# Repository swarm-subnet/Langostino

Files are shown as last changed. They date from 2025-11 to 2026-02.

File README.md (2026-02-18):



<!-- PROJECT BANNER -->
<p align="center">
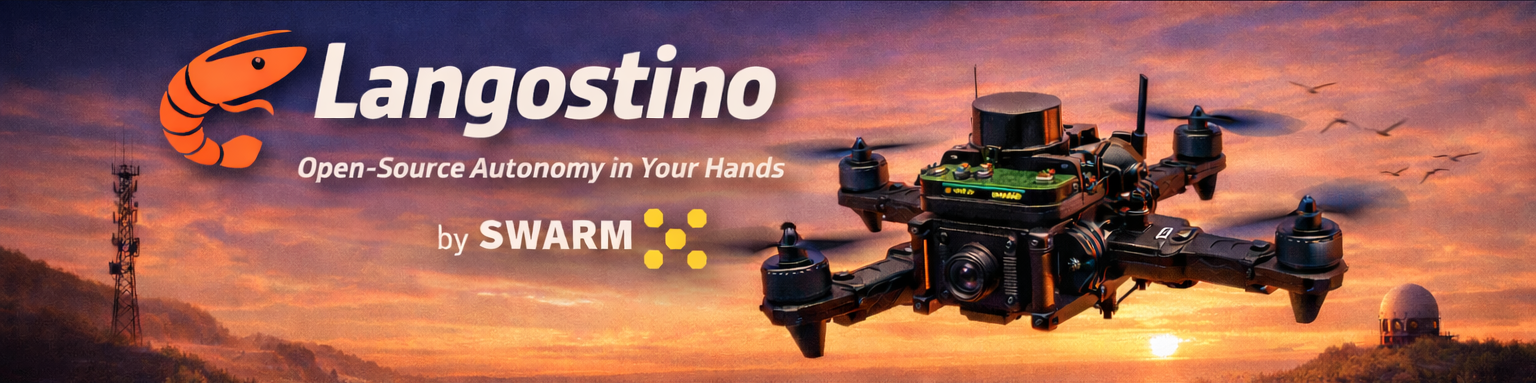
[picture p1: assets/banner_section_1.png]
Langostino — open autonomous drone
  
</p>

<h1 align="center">Langostino — The Swarm Drone</h1>

<p align="center">
  <b>Open-source AI autopilot for the real world: understand it, build it, and fly it.</b><br/>
  An open-source autonomous flight reference platform, built with a <b>global</b> community.
</p>

<!-- BADGES -->
<p align="center">
  <a href="https://github.com/swarm-subnet/Langostino/stargazers">
    
  </a>
  <a href="LICENSE.md">
    
  </a>
  
  <a href="https://discord.gg/txzvKMSd">
    
  </a>
</p>

<!-- QUICK ACTION BUTTONS -->
<p align="center">
  <a href="docs/assembly/README.md">
    
  </a>
  &nbsp;
  <a href="docs/SETUP_GUIDE.md#quick-setup">
    
  </a>
</p>

<!-- TABLE OF CONTENTS -->
<details>
  <summary><b>Table of Contents</b></summary>
  <ol>
    <li><a href="#see-it-in-action">See It In Action</a></li>
    <li><a href="#about-the-project">About The Project</a></li>
    <li><a href="#getting-started">Getting Started</a></li>
    <li><a href="#flight-plan">Flight Plan</a></li>
    <li><a href="#deep-dive-articles">Deep Dive Articles</a></li>
    <li><a href="#documentation">Documentation</a></li>
    <li><a href="#project-structure">Project Structure</a></li>
    <li><a href="#community">Community</a></li>
    <li><a href="#faq">FAQ</a></li>
    <li><a href="#share-pack">Share Pack</a></li>
    <li><a href="#license">License</a></li>
  </ol>
</details>

<!-- SEE IT IN ACTION -->
## See It In Action

### Assemble the drone and fly it autonomously

<p align="center">
  <b>"Build from scratch" drone holding its position</b>
</p>

<p align="center">
  <a href="https://www.youtube.com/shorts/gf9mxroeurU" target="_blank" rel="noopener noreferrer">
    Langostino position hold - click to watch
  </a>
</p>
<p align="center">
  <a href="https://www.youtube.com/shorts/gf9mxroeurU" target="_blank" rel="noopener noreferrer">
    
  </a>
</p>

<p align="center">
  <b>Fly it and improve it!</b>
</p>

<p align="center">
  <a href="https://www.youtube.com/watch?v=hTTbhE_WiQQ" target="_blank" rel="noopener noreferrer">
    Fly it and improve it - click to watch
  </a>
</p>
<p align="center">
  <a href="https://www.youtube.com/watch?v=hTTbhE_WiQQ" target="_blank" rel="noopener noreferrer">
    
  </a>
</p>

### Do it yourself, from ZERO!

<p align="center">
  <b>Example of what you will be building</b>
</p>

<p align="center">
  <a href="https://www.youtube.com/watch?v=jgdND4LXlIA" target="_blank" rel="noopener noreferrer">
    Langostino real flight — click to watch
  </a>
</p>
<p align="center">
  <a href="https://www.youtube.com/watch?v=jgdND4LXlIA" target="_blank" rel="noopener noreferrer">
    
  </a>
</p>

<p align="center">
  <sub>If this made you curious, star the repo and share the demo.</sub>
</p>

<p align="right">(<a href="#readme-top">back to top</a>)</p>

<!-- ABOUT THE PROJECT -->
## About The Project

Langostino is an **open-source reference drone** for real-world autonomous flight — designed to be easy to understand, build, and extend.

* **A practical AI autopilot project** focused on flying in the real world (not a black box)
* **A complete reference platform**: code, docs, and a clear path from "zero" to "first flight"
* **Made to be adapted**: use it as a starting point for your own drone and your own experiments
* **Community-driven**: built in the open, improved by builders and contributors worldwide

### Why It Matters

Autonomous drones shouldn't feel like magic or closed black boxes. Langostino exists to make real-world autonomy **understandable** and **buildable** — so more people can learn, iterate, and ship useful aerial systems.

By sharing a reference drone in the open, we lower the barrier from "curious" to "first flight", and turn progress into something the whole community can reuse.

### Built With

     

<p align="right">(<a href="#readme-top">back to top</a>)</p>

<!-- GETTING STARTED -->
## Getting Started

> [!CAUTION]
> **⚠️ Langostino is a real flying machine.**
> * Follow local regulations
> * Test in a safe environment responsibly and keep propellers off during bench tests.
> * Drones can cause injury and property damage. 
> * Use prop guards and appropriate failsafes

Pick what you want to do next — you don't need to be an expert to start.

<table>
  <tr>
    <td width="50%" valign="top">
      <h4>I'm just curious</h4>
      <ul>
        <li>Watch the demo (above)</li>
        <li>Star this repo</li>
        <li>Share it with a friend</li>
      </ul>
    </td>
    <td width="50%" valign="top">
      <h4>I want to build it from scratch</h4>
      <p><a href="docs/assembly/README.md"><b>Assembly Guide</b></a></p>
      <p><i>Includes the parts list (BOM) and step-by-step build instructions.</i></p>
    </td>
  </tr>
  <tr>
    <td width="50%" valign="top">
      <h4>I want to use the model</h4>
      <p><a href="docs/SETUP_GUIDE.md#quick-setup"><b>Setup Guide → Quick Setup</b></a></p>
    </td>
    <td width="50%" valign="top">
      <h4>I want to contribute</h4>
      <ul>
        <li>Join <a href="https://discord.gg/txzvKMSd">Discord</a></li>
        <li>Read <a href="CONTRIBUTING.md">CONTRIBUTING.md</a></li>
        <li>Pick a <a href="https://github.com/swarm-subnet/Langostino/issues?q=is%3Aissue+is%3Aopen+label%3A%22good+first+issue%22">good first issue</a></li>
      </ul>
    </td>
  </tr>
</table>

<p align="right">(<a href="#readme-top">back to top</a>)</p>

<!-- FLIGHT PLAN -->
## Flight Plan

Your path from zero to first flight:

1. **Get the parts** — Use the [BOM](docs/assembly/BOM.md) as your shopping list to source every component.

2. **Assemble the airframe** — Follow the build guide step-by-step. [Build guide →](docs/assembly/README.md)

3. **Install, then wire it up** — Follow the quickstart checklist step by step. [Quickstart →](docs/SETUP_GUIDE.md#quick-setup)

4. **Troubleshooting** — Diagnose setup, hardware, and runtime issues quickly with step-by-step checks. [Troubleshooting guide →](docs/TROUBLESHOOTING_GUIDE.md)

5. **Go outside & share** — Short flight, record a clip, star the repo, post your build. [Join Discord →](https://discord.gg/txzvKMSd)

<p align="center">
  <sub>Want the bigger picture? See the <a href="https://swarm124.com/decentralized-training">Swarm roadmap →</a></sub>
</p>

<p align="right">(<a href="#readme-top">back to top</a>)</p>

<!-- DEEP DIVE ARTICLES -->
## Deep Dive Articles

Want to understand the project in depth? Check out our Substack series that walks through every aspect of building and flying Langostino.

| Chapter | Topic | Description |
|---|---|---|
| [**Chapter 1**][chapter-1-url] | Inside the Drone | Hardware components and drone anatomy |
| [**Chapter 2**][chapter-2-url] | The Wiring Brain | Wiring, connections, and power distribution |
| [**Chapter 3**][chapter-3-url] | From Data to Motion | Software architecture and data flow |
| [**Chapter 3.5**][chapter-3.5-url] | Additional Configurations | Advanced configuration and tuning |

<p align="right">(<a href="#readme-top">back to top</a>)</p>

## Documentation

Find detailed guides for every aspect of the project.

| Category | Document | Description |
|---|---|---|
| **Building** | [Assembly Guide](docs/assembly/README.md) | Complete build guide from parts to first flight |
| | [Bill of Materials](docs/assembly/BOM.md) | Full parts list with purchase links |
| **INAV** | [INAV Configuration](docs/INAV_GUIDE.md) | Flight controller setup, PID tuning, MSP configuration |
| **ROS2** | [Setup Guide](docs/SETUP_GUIDE.md) | Ubuntu + ROS2 Humble installation on Raspberry Pi |
| | [Commands Guide](docs/COMMANDS_GUIDE.md) | ROS2 commands and node operations |
| | [Config Parameters](docs/CONFIG_PARAMS_GUIDE.md) | Complete ROS2 node configuration reference |
| **Tools** | [Map Proxy](mapproxy/README.md) | Offline map tile server for ground station |
| **Help** | [Troubleshooting](docs/TROUBLESHOOTING_GUIDE.md) | Common issues and solutions |
| | [Contributing](CONTRIBUTING.md) | How to contribute to the project |

<p align="right">(<a href="#readme-top">back to top</a>)</p>

<!-- PROJECT STRUCTURE -->
## Project Structure

<details open>
  <summary><b>Click to expand</b></summary>

```
swarm-ros/
├── src/
│   └── swarm_ai_integration/       # Main ROS2 package
│       ├── swarm_ai_integration/   # Python nodes (FC adapter, LiDAR, AI)
│       ├── config/                 # ROS2 parameter files
│       ├── launch/                 # Launch files
│       └── scripts/                # Utility scripts
├── scripts/
│   ├── setup_22_04.sh              # Ubuntu 22.04 setup script
│   ├── setup_24_04.sh              # Ubuntu 24.04 setup script
│   ├── network_setup_*.sh          # Network configuration scripts
│   ├── verify_setup.sh             # Installation verification
│   └── launch.sh                   # Quick launch script
├── docs/
│   ├── assembly/                   # Build guides and BOM
│   ├── SETUP_GUIDE.md              # ROS2 environment setup
│   ├── INAV_GUIDE.md               # Flight controller configuration
│   ├── COMMANDS_GUIDE.md           # ROS2 commands reference
│   ├── CONFIG_PARAMS_GUIDE.md      # Configuration parameters
│   └── TROUBLESHOOTING_GUIDE.md    # Common issues and fixes
├── assets/
│   └── 3D_print_STL/               # 3D printable parts (mounts, etc.)
├── inav-custom-firmware/           # Custom INAV firmware builds
├── mapproxy/                       # Offline map tile server
├── model/                          # AI model files
├── flight-logs/                    # Flight data logs
└── README.md                       # This file
```

</details>

<p align="right">(<a href="#readme-top">back to top</a>)</p>

<!-- COMMUNITY -->
## Community

Langostino is built with a **global** community of builders and contributors. If you're building, testing, or improving it — we want to hear from you.

<p align="center">
  <a href="https://discord.gg/txzvKMSd">
    
  </a>
</p>

<p align="center">
  <a href="https://discord.gg/txzvKMSd"><b>Discord</b></a>
  &nbsp;•&nbsp;
  <a href="https://x.com/SwarmSubnet"><b>X</b></a>
  &nbsp;•&nbsp;
  <a href="https://github.com/swarm-subnet"><b>GitHub</b></a>
</p>

<p align="center">
  <sub>Share your build log or flight clip in Discord — we feature the best builds.</sub>
</p>

<p align="right">(<a href="#readme-top">back to top</a>)</p>

<!-- FAQ -->
## FAQ

<details>
  <summary><b>Do I need to be an engineer?</b></summary>
  <p>No. Langostino is designed to be approachable: clear docs, a guided setup, and a community that can help you get started.</p>
</details>

<details>
  <summary><b>How do I get started?</b></summary>
  <p>Start with the <a href="docs/SETUP_GUIDE.md#quick-setup">Quick Setup Guide</a> if you already have compatible hardware. Otherwise, refer to the <a href="docs/assembly/README.md">Assembly Guide</a> for a list of materials and steps to follow. Join <a href="https://discord.gg/txzvKMSd">Discord</a> if you have any questions.</p>
</details>

<details>
  <summary><b>How do I contribute?</b></summary>
  <p>Join <a href="https://discord.gg/txzvKMSd">Discord</a>, check <a href="CONTRIBUTING.md">CONTRIBUTING.md</a>, and pick a <a href="https://github.com/swarm-subnet/Langostino/issues?q=is%3Aissue+is%3Aopen+label%3A%22good+first+issue%22">good first issue</a>.</p>
</details>

<p align="right">(<a href="#readme-top">back to top</a>)</p>

<!-- SHARE PACK -->
## Share Pack

Want to help Langostino reach more builders? Copy/paste one of these.

<details>
  <summary><b>X (Twitter)</b></summary>

  ```
  Open-source AI autopilot for real-world drones

  Langostino is a reference drone you can understand, build, and fly — built with a global community.

  https://github.com/swarm-subnet/Langostino
  ```
</details>

<details>
  <summary><b>Where to share</b></summary>

  * **Hackaday** — open hardware / DIY audience
  * **DIY Drones** — builders who actually fly
  * **Reddit** — consider: r/drones, r/Multicopter, r/robotics (follow each subreddit's rules)
</details>

<p align="right">(<a href="#readme-top">back to top</a>)</p>

<!-- LICENSE -->
## License

Distributed under the MIT License. See [LICENSE](LICENSE.md) for more information.

<p align="right">(<a href="#readme-top">back to top</a>)</p>

---

<p align="center">
  <b>Happy flying!</b>
</p>

<!-- MARKDOWN LINKS -->
[chapter-1-url]: https://substack.com/home/post/p-175604069
[chapter-2-url]: https://substack.com/home/post/p-176136139
[chapter-3-url]: https://substack.com/home/post/p-177453660
[chapter-3.5-url]: https://substack.com/home/post/p-180586067

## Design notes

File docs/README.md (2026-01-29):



# Docs folder

Quick reference index for all documentation in this folder.

## Overview

This folder contains all the documentation for setting up, configuring, and troubleshooting the Langostino drone system. Documents are organized by topic area.

## Documents Index

| Document | Description |
|---|---|
| [**assembly/**](assembly/README.md) | Complete build guide and Bill of Materials for assembling the drone from scratch |
| [**SETUP_GUIDE.md**](SETUP_GUIDE.md) | Step-by-step ROS2 environment setup on Ubuntu 22.04/24.04 for Raspberry Pi |
| [**INAV_GUIDE.md**](INAV_GUIDE.md) | Flight controller configuration: PID tuning, MSP settings, navigation parameters |
| [**COMMANDS_GUIDE.md**](COMMANDS_GUIDE.md) | Quick reference for ROS2 launch commands, PM2 management, and node operations |
| [**CONFIG_PARAMS_GUIDE.md**](CONFIG_PARAMS_GUIDE.md) | Complete reference for all ROS2 node parameters in `swarm_params.yaml` |
| [**TROUBLESHOOTING_GUIDE.md**](TROUBLESHOOTING_GUIDE.md) | Common issues and solutions for hardware, software, and network problems |

## Getting Started

**New to the project?** Start here:

1. **Building the drone** → [Assembly Guide](assembly/README.md)
2. **Setting up the software** → [Setup Guide](SETUP_GUIDE.md)
3. **Configuring the flight controller** → [INAV Guide](INAV_GUIDE.md)
4. **Running the system** → [Commands Guide](COMMANDS_GUIDE.md)

<p align="right">(<a href="#readme-top">back to top</a>)</p>

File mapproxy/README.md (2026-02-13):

# MapProxy - Satellite image map server

MapProxy, a local tile caching proxy for ArcGIS World Imagery satellite tiles. Provides satellite imagery for INAV Configurator's Mission Control with local caching to reduce bandwidth and improve loading times (so you can use it even without internet connection). If you plan to fly somewhere that is not shown on a street/basic map, you need this satellite image map.

## Installation

```bash
cd mapproxy

# Create virtual environment
python3 -m venv venv

# Activate virtual environment
source venv/bin/activate

# Install dependencies
pip install -r requirements.txt
```

## Usage

### Start the server

```bash
./launch_mapproxy.sh
```

Or manually:
```bash
source venv/bin/activate
mapproxy-util serve-develop mapproxy.yaml -b 0.0.0.0:8080
```

The server will be available at `http://localhost:8080`.

### INAV Configurator Setup

In INAV Configurator, go to **Mission Control** and configure:

| Setting | Value |
|---|---|
| Map Provider | `MapProxy` |
| MapProxy URL | `http://127.0.0.1:8080/service` |
| MapProxy Layer | `arcgis_sat` |

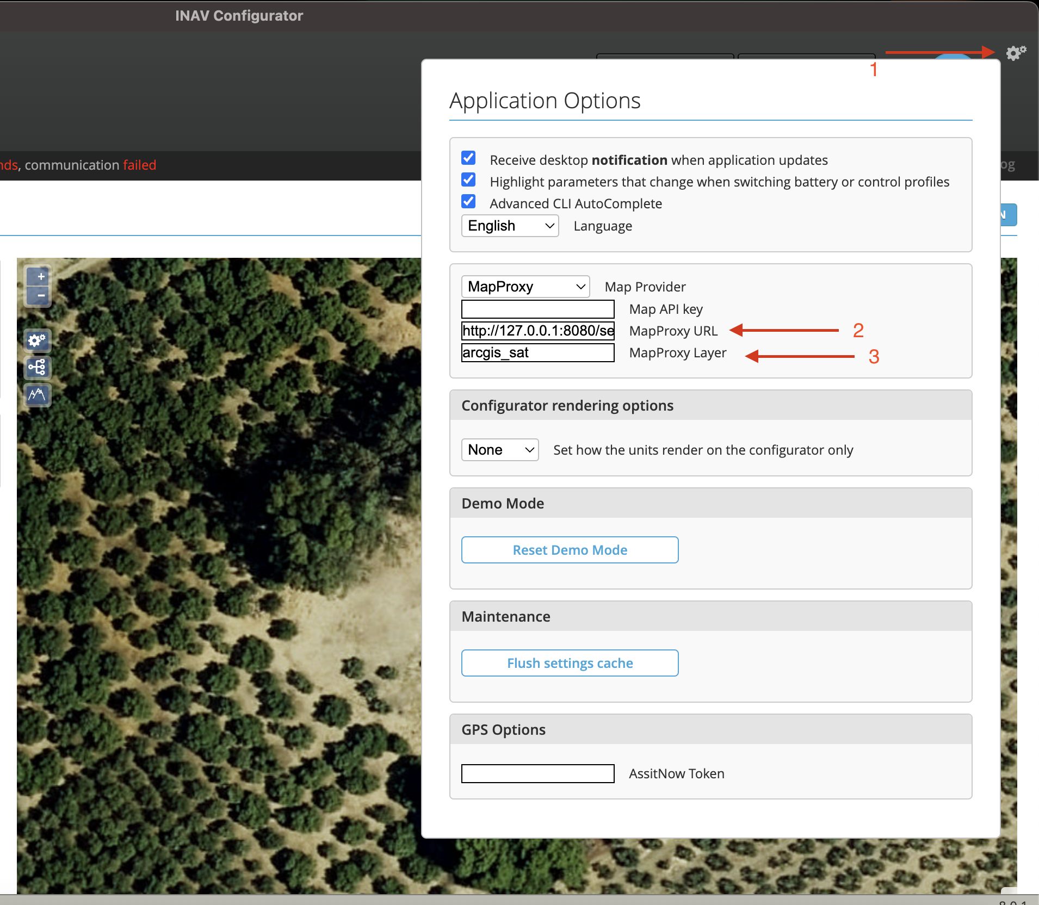
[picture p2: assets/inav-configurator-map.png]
Step to configure mapproxy on INAV configurator

_Step to configure mapproxy on INAV configurator_

### Available endpoints for testing

| Service | URL |
|---|-----|
| Demo/Preview | http://localhost:8080/demo/ |
| WMS | http://localhost:8080/service?SERVICE=WMS&REQUEST=GetCapabilities |

## Cache

Tiles are cached in `./cache_data/`. Delete this folder to clear the cache.

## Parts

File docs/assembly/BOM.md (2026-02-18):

# Parts list (BOM) — Langostino 🦐

This BOM is the parts list for a Langostino-compatible 6" quadcopter and the onboard autonomy stack (Raspberry Pi + ROS2).

## Scope

This list covers:
- All parts required to build the drone.
- Radio transmitter
- Onboard computer for ROS2 + AI stack
- Sensors and power supplier for reliable autonomy

## Core build (required)

### 1) Frame

| Part | Qty | Link | Notes |
|---|---:|---|---|
| FlyFishRC Volador II VD6 (6" carbon frame) | 1 | https://www.aliexpress.com/item/1005009244888358.html | 6" frame durable with enough room for onboard computer + sensors. |

### 2) Motors and propellers

| Part | Qty | Link | Notes |
|---|---:|---|---|
| iFlight XING-E Pro 2306 1700KV brushless motors | 4 | https://www.aliexpress.com/item/1005008310935904.html | Sized for 6" class builds. |
| HQProp 6x3x3 propellers (6CW/6CCW, 12pcs) | 1 pack | https://www.aliexpress.com/item/1005009859783537.html | Keep spare propellers for testing and tuning. |

### 3) Stack Flight controller + ESC

| Part | Qty | Link | Notes |
|---|---:|---|---|
| SpeedyBee F405 V4 + 55A 4-in-1 ESC stack (30x30) | 1 | https://www.aliexpress.com/item/1005010224729199.html | Flight controller + ESC stack. Compatible with INAV. |

### 4) GPS and compass module

| Part | Qty | Link | Notes |
|---|---:|---|---|
| HGLRC M10 GPS module + compass | 1 | https://www.aliexpress.com/item/1005008492407753.html | GPS/compass for navigation modes. Mount away from high-current wiring. |

### 5) ERLS radio transmitter and receiver

| Part | Qty | Link | Notes |
|---|---:|---|---|
| RadioMaster Boxer 2.4G ELRS transmitter | 1 | https://www.aliexpress.com/item/1005005476887648.html | Elrs and multichannel radio transmitter. |
| SpeedyBee Nano ExpressLRS receiver | 1 | https://www.aliexpress.com/item/1005009188594963.html| Receiver installed on the drone. |

### 6) Battery

| Part | Qty | Link | Notes |
|---|---:|---|---|
| Ovonic 4S LiPo 1300mAh 100C (XT60) | 1+ | https://www.aliexpress.com/item/1005009034486146.html| One battery is enough to start; multiple packs recommended for iteration. |

## Autonomy stack

### 7) Onboard computer

| Part | Qty | Link | Notes |
|---|---:|---|---|
| Raspberry Pi 5 (4GB/8GB) + case/fan | 1 | https://www.aliexpress.com/item/1005006268136678.html | Runs Ubuntu 24.04 + ROS2 Jazzy. Ensure adequate cooling. |

### 8) Clean 5V power (critical)

| Part | Qty | Link | Notes |
|---|---:|---|---|
| UBEC / switching regulator 5V (≥5A recommended) | 1 | https://www.aliexpress.com/item/1005009452713815.html | Stable 5V rail for Pi + sensors. Prefer ≥5A for Pi 5 headroom. |

## Sensors

| Part | Qty | Link | Notes |
|---|---:|---|---|
| LiDAR ToF (front-facing) | +3 | https://www.aliexpress.com/item/1005008738338495.html| Used for obstacle distance. Interface depends on model (I²C/UART). |

---

## Safety & field essentials

| Part | Qty | Link | Notes |
|---|---:|---|---|
| Autonomous buzzer / lost model buzzer | 1 | https://www.aliexpress.com/item/1005009383497649.html | Helps locate the drone after crashes or unexpected landings. It works even if the battery has been desconnected |
| Low-ESR filtering 35v 2200µf capacitor (power line) | 2 | https://www.aliexpress.com/item/1005003820087840.html| Reduces electrical noise and voltage spikes from motors/ESC. |

## Storage, wiring, and build consumables

| Part | Notes |
|---|---|
| microSD OS | 64GB min to store OS + proyect + logs
| Ethernet cable (field debugging) | Useful for direct connection to ethernet-ethernet. |
| Silicone wire awg 12 for and awg 16 for signals, heatshrink, zip ties | 
| Battery straps + foam pad | Secures LiPo during impact and vibration. |
| 3D printer | Recommended to print the files present in the `assets/3D_print_STL` folder. |

## Optional spares

| Part | Qty | Notes |
|---|---:|---|
| Extra propeller packs | 1+ | Propellers are consumables during testing. |
| Extra batteries | 1+ | More flight time per session. |

## Notes on compatibility

- This BOM targets a 6" class build (VD6 frame, 2306 motors, 6" props).
- INAV is used for navigation/autonomy features and MSP control paths.
- The autonomy stack assumes Ubuntu 25.04 + ROS2 Jazzy on a Raspberry Pi 5.

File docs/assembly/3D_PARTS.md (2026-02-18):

# 3D Printed Parts Guide

Custom 3D printed parts for mounting sensors and the companion computer on the drone frame.

> **Note:** The Raspberry Pi mount is designed for **Raspberry Pi 5**. A Raspberry Pi 3 does not fit due to the audio jack interfering with the case geometry. A version compatible with the Raspberry Pi 3 is coming soon.

---

## STL Files Location

All printable files are located in:

```
/assets/3D_print_STL/
```

---

## Parts List

### `drone-down-lidar-base.stl`

Base mount for the downward-facing LiDAR sensor. Attaches to the bottom of the drone frame.

---

### `drone-front-lidar-base.stl`

Base mount for the front-facing LiDAR sensor. On this frame, it mounts in the position originally designed for the GoPro mount.

---

### `drone-leg.stl`

Landing leg extension that fits onto the frame arm. Prevents the sensors mounted underneath from touching the ground during landing.

---

### `drone-lidar-mount.stl`

Universal LiDAR sensor mount used in both the downward and front positions. Designed so the sensor can be articulated, allowing its angle to be adjusted.

---

### `drone-raspberry-onboard-case.stl`

Case for mounting the Raspberry Pi 5 on the underside of the drone. It attaches using the screws on the lower front of the frame — the same screws that hold the metal parts originally designed for the FPV video system.

---

## Assembly Notes

The remaining components (ESCs, flight controller, receiver, etc.) should be assembled using **cable ties** and **hot silicone**, always ensuring that all parts are securely attached.

**Electromagnetic interference:** Components sensitive to electromagnetic fields, such as the **GPS** and **magnetometer**, should be mounted as far away as possible from the battery cables. For this reason:

- The **XT60 connector** is placed on the **side of the frame**.
- The **battery** is positioned **as far forward as possible**.

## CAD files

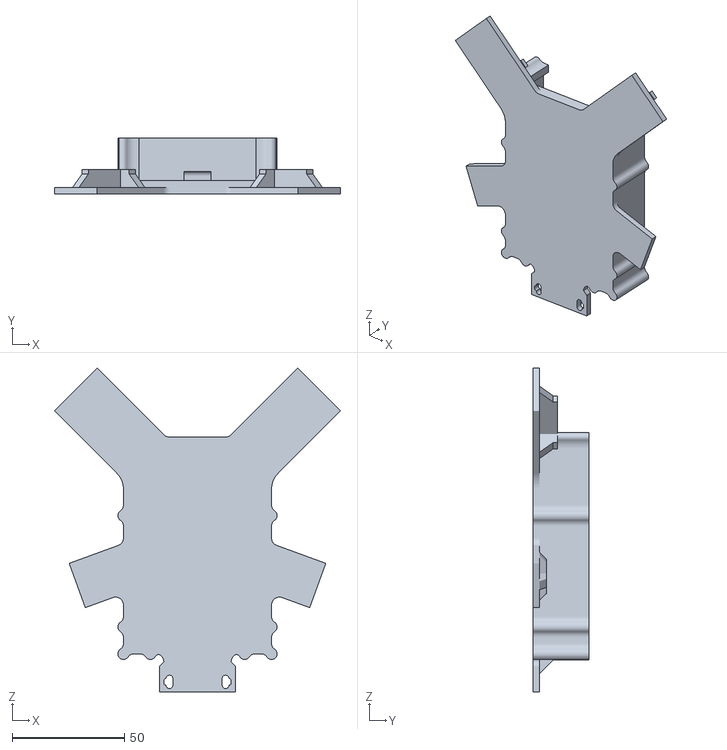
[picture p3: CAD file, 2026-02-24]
assets/3D_print_STL/drone-raspberry-onboard-case.stl
127.5 x 25.0 x 144.4

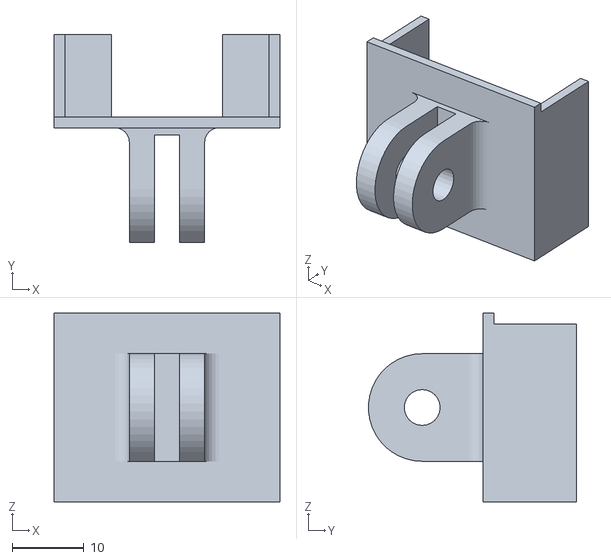
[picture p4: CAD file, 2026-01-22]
assets/3D_print_STL/drone-lidar-mount.stl
31.5 x 29.0 x 26.3

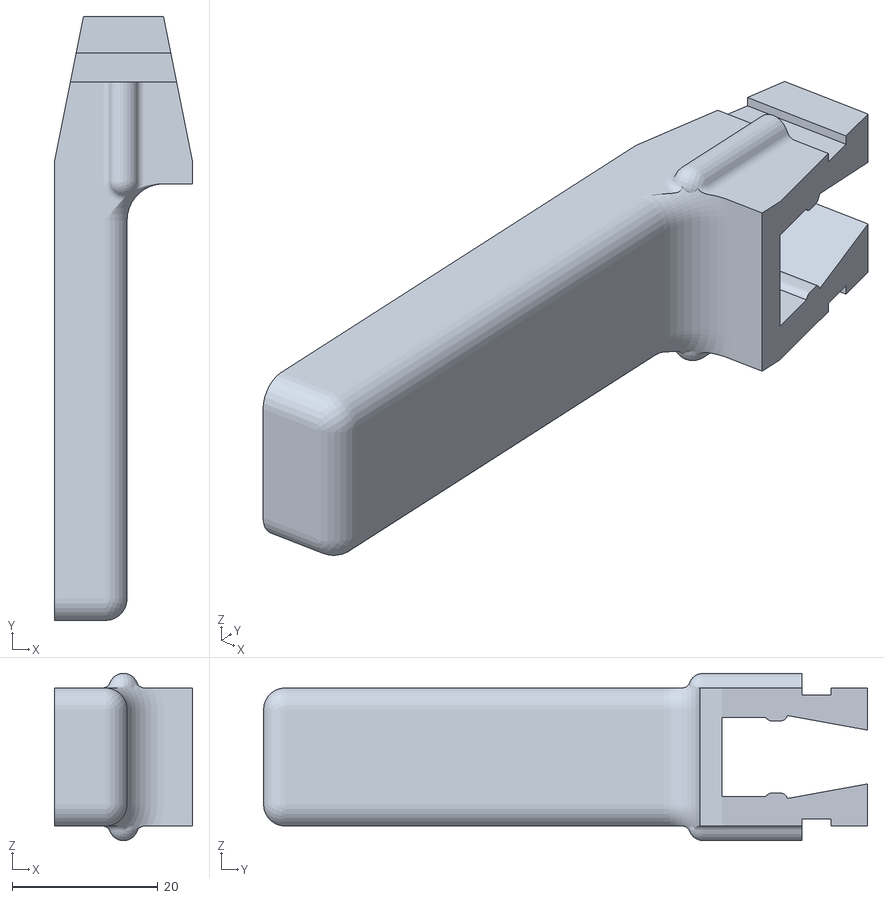
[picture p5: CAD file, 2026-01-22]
assets/3D_print_STL/drone-leg.stl
19.0 x 83.0 x 23.0

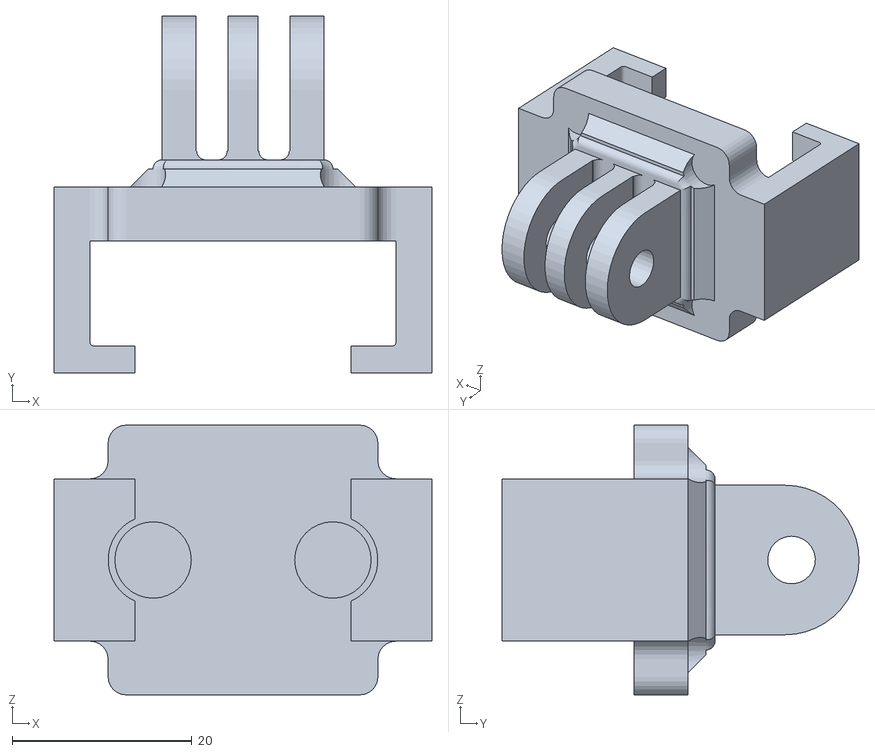
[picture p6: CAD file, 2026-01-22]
assets/3D_print_STL/drone-down-lidar-base.stl
42.0 x 39.7 x 30.0

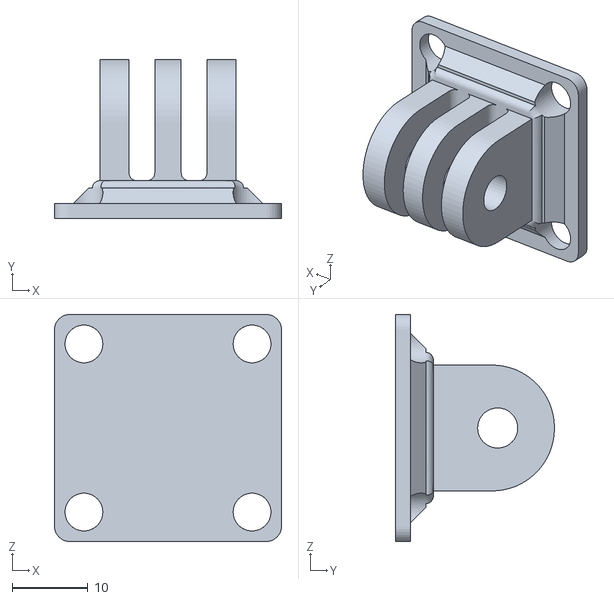
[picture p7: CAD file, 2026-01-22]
assets/3D_print_STL/drone-front-lidar-base.stl
30.0 x 21.0 x 30.0

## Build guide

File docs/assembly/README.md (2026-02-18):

# Build from scratch — Assembly guide 🦐

This guide is your “flight plan” to go from parts → build → first safe flight.

> [!CAUTION]
> **⚠️ Langostino is a real flying machine.**
> * Follow local regulations
> * Test in a safe enviroment responsibly and keep propellers off during bench tests.
> * Drones can cause injury and property damage. 
> * Use prop guards and appropriate failsafes

## Step 0 — Before you start

### Tools (typical)

- Hex drivers / screw set (FPV frame hardware)
- Soldering iron + soldering tin and flux + heatshrink
- Zip ties / cable sleeves (strain relief matters)
- Multimeter (recommended)
- Hot glue gun (recommended).
- Laptop with INAV Configurator installed and type-C USB

## Step 1 — Parts (BOM)

Open: [`./BOM.md`](./BOM.md)

The BOM is your shopping list. It should include:

- Frame
- FC/ESC stack
- Motors + propellers
- Raspberry Pi + microSD card
- LiDAR (down at least, more optional) + 3d printed mounts
- GPS/compass module
- 5V regulator + filtering capacitor
- Receiver
- Autonomous buzzer

## Step 2 — The skeleton (frame) + motors

### 2.1 Build the frame

- Assemble the carbon frame (arms, plates, standoffs)
- Keep it **rigid**: vibrations = noisy data for sensors/AI
- Leave room for: FC stack, wiring, Pi, LiDAR mounts

### 2.2 Mount motors + props (props last)

- Mount motors securely (use thread lock if needed)
- **Do not install propellers yet** — leave them off until the end

### 2.3 Install the FC + ESC stack

- Mount the stack with vibration-damping hardware if available
- Ensure access to:
  - USB port (flashing/config)
  - UART pads/ports (GPS/MSP/etc.)
  - power leads (battery input)

> Why INAV: unlike Betaflight (manual-first), **INAV** is built for navigation/autonomy and supports MSP-based control paths.

## Step 3 — Sensors + “field” essentials

### 3.1 LiDAR

- Install LiDAR downward-facing (front-facing optional)
- Use stable mounts (3D-printed mounts help reduce vibration + keep alignment)
- Keep cables tidy and strain-relieved
- See [`3D_PARTS.md`](./3D_PARTS.md) for printable sensor mounts and assembly notes

### 3.2 GPS

- Mount the GPS with good sky visibility
- Keep it away from noisy power lines, like awg 12 battery wires if possible

### 3.3 Receiver

- Install a receiver so you can always take back control
- Confirm that you have a good control before autonomy flights

### 3.4 Autonomous buzzer (highly recommended)

- Install an autonomous buzzer connected to the FC on BZ+ and BZ-.
- Purpose: finding the drone after unexpected landings/crashes

## Step 4 — Wiring (power + data)

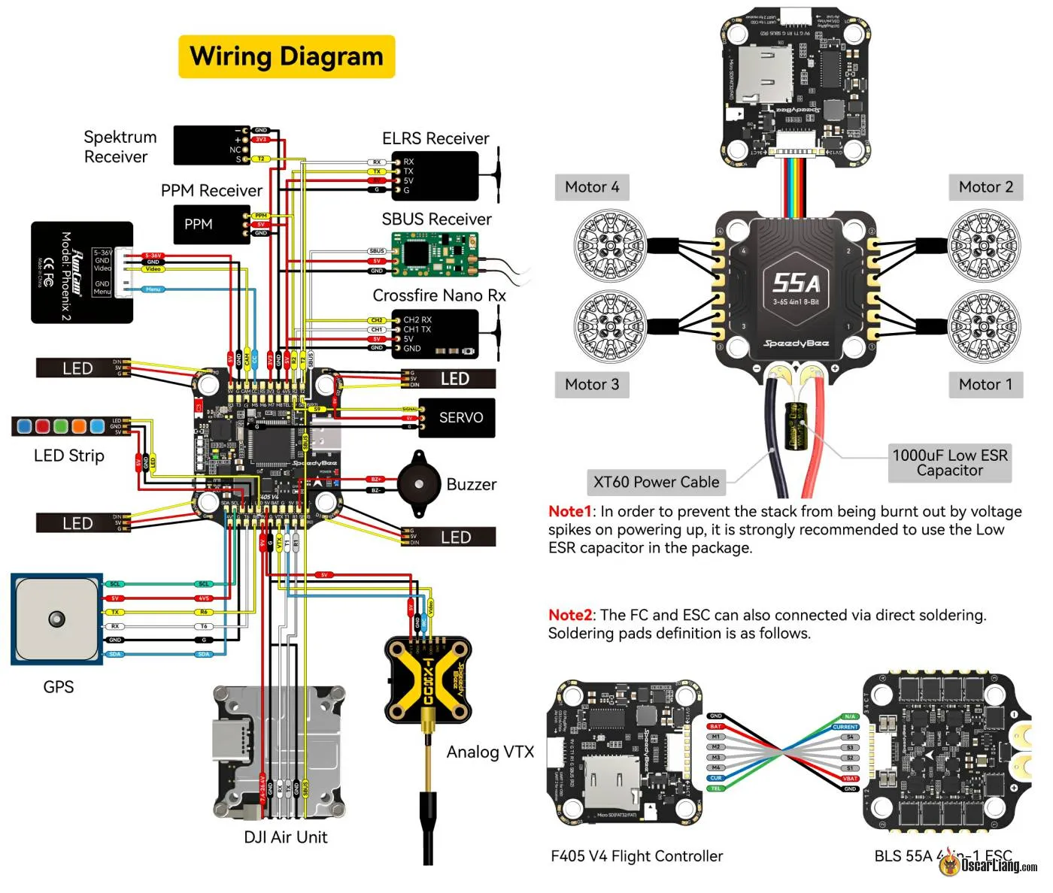
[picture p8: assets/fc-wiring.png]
SpeedyBee F405 V4 wiring diagram

_SpeedyBee F405 V4 wiring diagram_

This is where "circuits meet code".

> 📖 **Deep Dive:** For a detailed walkthrough of the wiring and connections, see [Chapter 2: The Wiring Brain](https://substack.com/home/post/p-176136139) on our Substack.

### 4.1 Clean power (very important)

- Battery feeds ESC → motors
- A regulator steps down high voltage to **clean 5V** for the Raspberry Pi.
- Add a **filtering capacitor** on the power line:
  - reduces electrical noise from motors
  - helps protect electronics from voltage spikes

> If power is noisy, sensors can drift and the AI can “react” to bad data.

### 4.2 Data buses: UART + I²C

#### UART (direct “hotline”)

Used for FC ↔ Raspberry Pi (telemetry + commands).

- On the Pi, stable device paths often look like `/dev/ttyAMA0` / `/dev/ttyAMA1`
- Keep UART wiring short/clean where possible

##### FC UART assignments

| UART | Function |
|---|---|
| UART 2 | ELRS receiver |
| UART 3 | FC to Raspberry Pi communications |
| UART 4 | Not used |
| UART 5 | Internal telemetry with ESCs |
| UART 6 | GPS and compass |

#### I²C (shared "group chat")

Used for multiple sensors on the same bus.

- LiDAR modules communicate via I²C
- Each has its own address so they don't collide

#### Raspberry Pi 5 GPIO Connections

<p align="center">
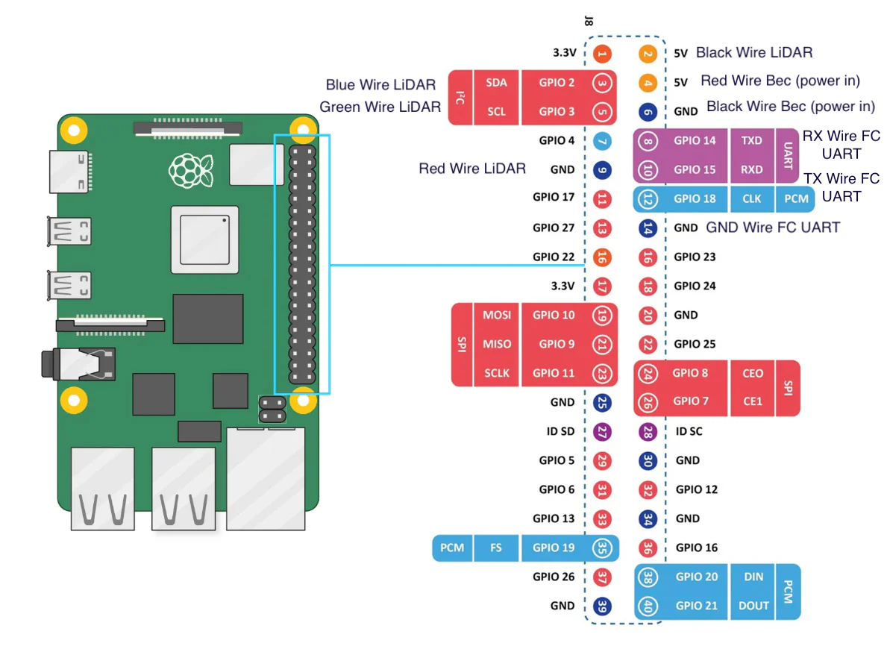
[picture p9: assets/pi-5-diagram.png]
Raspberry Pi 5 GPIO diagram
  
</p>

| Pin | Function | Connection |
|-----|---|---|
| 2 | 5V VCC | LiDAR power |
| 3 | SDA (I²C) | LiDAR SDA |
| 4 | 5V | Raspberry Pi power input |
| 5 | SCL (I²C) | LiDAR SCL |
| 6 | GND | Raspberry Pi power GND |
| 8 | TXD (UART) | FC RX |
| 9 | GND | LiDAR GND |
| 10 | RXD (UART) | FC TX |
| 14 | GND | FC UART GND |

> **Note:** TXD → RX and RXD → TX: UART lines cross between devices.

## Step 5 — Raspberry Pi software (Ubuntu + ROS2 + Swarm stack)

Follow the quick setup:
[`../SETUP_GUIDE.md#quick-setup`](../SETUP_GUIDE.md#quick-setup)

In most cases you’ll run:

```bash
sudo ./setup.sh
./verify_setup.sh
./launch.sh
```

If you hit issues, go to:
[`../TROUBLESHOOTING_GUIDE.md`](../TROUBLESHOOTING_GUIDE.md)

## Step 6 — INAV setup (firmware + parameters + MSP path)

### 6.1 Flash INAV (if not already)

- Use INAV Configurator firmware flasher
- Flash a supported INAV build for your flight controller. For SpeedyBee F405 V4, use our custom firmware: [`inav_8.0.1_SPEEDYBEEF405V4.hex`](../../inav-custom-firmware/inav_8.0.1_SPEEDYBEEF405V4.hex)
- Reboot and confirm the FC connects properly

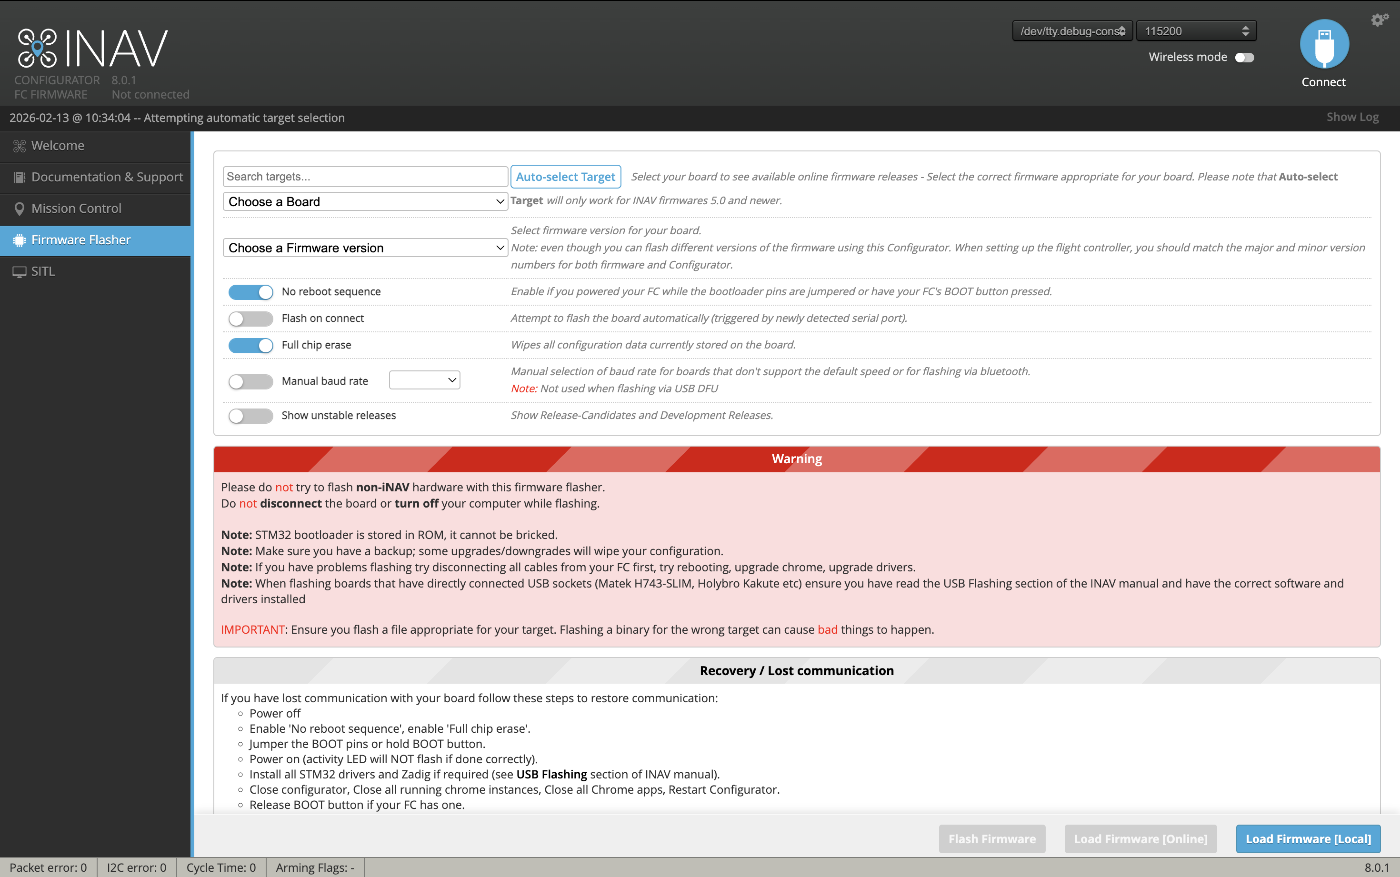
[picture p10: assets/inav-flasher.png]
Flasher option of INAV configurator

_Flasher option of INAV configurator_

### 6.2 Apply baseline parameters (copy/paste script)

Use:
[`../INAV_GUIDE.md#complete-configuration-script-inav-cli-commands`](../INAV_GUIDE.md#complete-configuration-script-inav-cli-commands)

### 6.3 MSP / RC override

From [`../INAV_GUIDE.md#msp-configuration`](../INAV_GUIDE.md#msp-configuration):

- `msp_override_channels` defines which RC channels can be overridden via MSP.

**Build-guide checklist (repo-confirmed + typical practice):**

- Configure your INAV parameters (script above)
- Set `msp_override_channels` as documented (e.g. `127` or `255` depending on your channel plan)
- Ensure you have a working manual override (radio receiver) before autonomy tests

> Note: enabling MSP/override end-to-end often involves both **parameters** (like `msp_override_channels`) and **port configuration** in INAV Configurator. Port specifics vary by FC and wiring.

## First flights (do this in order)

### Bench test (props off)

- Power on, confirm FC boots normally
- Confirm sensors are detected (as per setup docs)
- Run [`../../scripts/verify_setup.sh`](../../scripts/verify_setup.sh)
- Confirm launch is stable and logs are clean
- Confirm motor spin direction. Set reverse motor spin direction to follow this diagram:

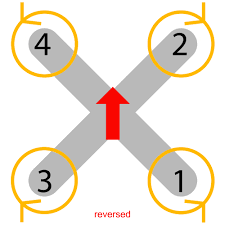
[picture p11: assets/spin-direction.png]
Spin direction

_Drone motor spin direction_

> **Fixing wrong motor direction:** If any motor spins the wrong way, you can reverse it using the [ESC Configurator](https://esc-configurator.com). Connect the FC via USB, open the tool in a Chrome-based browser, select your ESC firmware (BLHeli_S / BLHeli_32 / AM32), and toggle the **Motor Direction** for the affected motor(s). Flash the updated settings and verify the correct spin direction.

### Manual flight first

Before autonomy:

- Confirm arming checks pass
- Confirm vibrations are reasonable
- Confirm GPS meets minimum sats and is stable
- Confirm flight mode works

### Then autonomy experiments

- Start conservative
- Keep safe altitude and space
- Log everything and iterate

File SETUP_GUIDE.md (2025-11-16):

# Swarm ROS2 Environment Setup Guide

This guide provides step-by-step instructions for setting up the complete Swarm AI Integration drone control system on Ubuntu 22.04.

## Table of Contents

- [Prerequisites](#prerequisites)
- [Quick Setup](#quick-setup)
- [Manual Setup](#manual-setup)
- [Hardware Configuration](#hardware-configuration)
- [Verification](#verification)
- [Troubleshooting](#troubleshooting)

---

## Prerequisites

### Hardware Requirements
- **Flight Controller**: INAV 7 compatible (connected via UART/Serial)
- **LiDAR Sensor**: I2C-based distance sensor (e.g., TFMini-S on address 0x08)
- **Onboard Computer**: Raspberry Pi 4 or Ubuntu 22.04 server
- **GPS Module**: Connected to flight controller
- **IMU**: Integrated in flight controller

### Software Requirements
- **OS**: Ubuntu 22.04 LTS (Jammy Jellyfish)
- **Internet Connection**: For downloading packages
- **Sudo Access**: Root privileges required for installation

### Hardware Connections
| Component | Interface | Device Path | Notes |
|---|---|---|---|
| Flight Controller | UART/Serial | `/dev/ttyAMA0` | 115200 baud |
| LiDAR (Down) | I2C Bus 1 | Address `0x08` | 100Hz polling |
| GPS | via FC | - | MSP protocol |
| IMU | via FC | - | MSP protocol |

---

## Quick Setup

### 1. Clone the Repository

```bash
cd ~
git clone <your-repo-url> swarm-ros
cd swarm-ros
```

### 2. Run Setup Script

```bash
sudo ./setup.sh
```

**What it does:**
- ✅ Installs ROS2 Humble (if needed)
- ✅ Installs all dependencies (Python, I2C, UART)
- ✅ Creates Python virtual environment for AI packages
- ✅ Configures hardware permissions (I2C, UART)
- ✅ **Configures network (WiFi AP + Ethernet static IP)**
- ✅ **Fixes workspace ownership** (prevents permission errors)
- ✅ Builds ROS2 workspace
- ✅ Installs PM2 process manager (auto-start on boot)

**Available Options:**
- `--skip-ros`: Skip ROS2 installation (if already installed)
- `--skip-hardware-check`: Skip hardware connectivity checks
- `--skip-pm2`: Skip PM2 installation (installed by default)

**Example with options:**
```bash
# Skip PM2 if you don't want process management
sudo ./setup.sh --skip-pm2

# Skip ROS2 install if already present
sudo ./setup.sh --skip-ros
```

> **Note**: The script automatically fixes workspace permissions and cleans old build artifacts, preventing common `colcon build` permission errors.

### 3. Log Out and Back In

**Important**: You must log out and log back in for group changes to take effect!

```bash
logout
# Or reboot
sudo reboot
```

### 4. Verify Installation

```bash
cd ~/swarm-ros
./verify_setup.sh
```

### 5. Launch the System

**Option A: Using PM2 (Recommended - Auto-installed)**

```bash
# Launch with PM2 process manager
./launch.sh

# View status
pm2 list

# View logs in real-time
pm2 logs

# Stop the system
pm2 stop swarm-ros-launched
```

**Option B: Direct ROS2 Launch**

```bash
# Source the environment (if not in .bashrc)
source /opt/ros/humble/setup.bash
source ~/swarm-ros/install/setup.bash

# Launch directly (runs in foreground)
ros2 launch swarm_ai_integration swarm_ai_launch.py
```

> **PM2 Benefits**: Auto-restart on crash, survives reboots, centralized logging, resource monitoring

---

## Manual Setup

If you prefer to set up components individually:

### Step 1: Install ROS2 Humble

```bash
# Set up locale
sudo apt update && sudo apt install -y locales
sudo locale-gen en_US en_US.UTF-8
sudo update-locale LC_ALL=en_US.UTF-8 LANG=en_US.UTF-8

# Add ROS2 apt repository
sudo apt install -y software-properties-common
sudo add-apt-repository universe
sudo apt update && sudo apt install -y curl gnupg lsb-release

curl -sSL https://raw.githubusercontent.com/ros/rosdistro/master/ros.key \
  -o /usr/share/keyrings/ros-archive-keyring.gpg

echo "deb [arch=$(dpkg --print-architecture) signed-by=/usr/share/keyrings/ros-archive-keyring.gpg] \
  http://packages.ros.org/ros2/ubuntu $(source /etc/os-release && echo $UBUNTU_CODENAME) main" \
  | sudo tee /etc/apt/sources.list.d/ros2.list > /dev/null

# Install ROS2
sudo apt update
sudo apt install -y ros-humble-ros-base
sudo apt install -y ros-dev-tools python3-colcon-common-extensions

# Initialize rosdep
sudo rosdep init
rosdep update
```

### Step 2: Install System Dependencies

```bash
sudo apt install -y \
    build-essential \
    cmake \
    git \
    python3-pip \
    python3-dev \
    python3-venv \
    libi2c-dev \
    i2c-tools \
    python3-smbus \
    python3-serial \
    python3-numpy \
    python3-scipy
```

### Step 3: Install Python Dependencies

**System packages (for ROS nodes):**
```bash
pip3 install --upgrade pip
pip3 install numpy scipy pyserial smbus2
```

**Virtual environment for AI Flight Node:**
```bash
# Create virtual environment
python3 -m venv ~/ai_flight_node_env

# Activate virtual environment
source ~/ai_flight_node_env/bin/activate

# Install AI packages from requirements file
cd ~/swarm-ros
pip install --upgrade pip
pip install -r ai_model_requirements.txt

# Deactivate (optional)
deactivate
```

The `ai_model_requirements.txt` file contains:
- numpy>=1.24,<2.0
- typing-extensions
- gymnasium
- stable-baselines3
- torch

### Step 4: Configure I2C (for LiDAR)

```bash
# Enable I2C module
sudo modprobe i2c-dev
echo "i2c-dev" | sudo tee -a /etc/modules

# Add user to i2c group
sudo usermod -a -G i2c $USER

# Set I2C permissions
echo 'KERNEL=="i2c-[0-9]*", GROUP="i2c", MODE="0660"' \
  | sudo tee /etc/udev/rules.d/99-i2c.rules

sudo udevadm control --reload-rules
sudo udevadm trigger
```

### Step 5: Configure UART (for Flight Controller)

```bash
# Add user to dialout group
sudo usermod -a -G dialout $USER

# Set UART permissions
cat << EOF | sudo tee /etc/udev/rules.d/99-serial.rules
KERNEL=="ttyAMA[0-9]*", GROUP="dialout", MODE="0660"
KERNEL=="ttyUSB[0-9]*", GROUP="dialout", MODE="0660"
KERNEL=="ttyACM[0-9]*", GROUP="dialout", MODE="0660"
EOF

sudo udevadm control --reload-rules
sudo udevadm trigger
```

### Step 6: Configure Network (WiFi AP + Ethernet)

```bash
# Run the network setup script
cd ~/swarm-ros
chmod +x network_setup.sh
sudo ./network_setup.sh
```

**What it configures:**
- Static IP on `eth0`: `192.168.10.1/24`
- DHCP on `wlan0` for connecting to known WiFi networks
- Automatic WiFi Access Point fallback
- AP SSID: `Swarm_AP`
- AP Password: `swarmascend`
- DHCP server range: `192.168.10.10 - 192.168.10.50`
- Automatic network manager service

The system will automatically:
1. Try to connect to known WiFi networks on boot
2. If no known network is found, create an Access Point
3. Allow you to SSH into the drone at `192.168.10.1`

To add known WiFi networks, edit `/etc/wifi_networks.conf`:
```bash
sudo nano /etc/wifi_networks.conf
```

Add networks in the format:
```
SSID:password
MyHomeWiFi:mypassword123
WorkNetwork:workpassword
```

### Step 7: Build ROS2 Workspace

```bash
cd ~/swarm-ros
source /opt/ros/humble/setup.bash
rosdep install --from-paths src --ignore-src -r -y
colcon build --symlink-install
```

### Step 8: Configure Environment

Add to `~/.bashrc`:

```bash
# ROS2 Environment
source /opt/ros/humble/setup.bash
source ~/swarm-ros/install/setup.bash

# ROS2 Configuration
export ROS_DOMAIN_ID=0
export ROS_LOCALHOST_ONLY=0
```

Apply changes:
```bash
source ~/.bashrc
```

---

## Hardware Configuration

### I2C LiDAR Setup

#### Enable I2C on Raspberry Pi

Edit `/boot/firmware/config.txt`:
```bash
sudo nano /boot/firmware/config.txt
```

Add or uncomment:
```
dtparam=i2c_arm=on
```

Reboot:
```bash
sudo reboot
```

#### Verify I2C Connection

Check if I2C device is detected:
```bash
i2cdetect -y 1
```

You should see `08` in the output grid (LiDAR address).

### UART Flight Controller Setup

#### Enable UART on Raspberry Pi

Edit `/boot/firmware/config.txt`:
```bash
sudo nano /boot/firmware/config.txt
```

Add:
```
enable_uart=1
```

#### Disable Serial Console (if needed)

Edit `/boot/firmware/cmdline.txt` and remove:
```
console=serial0,115200
```

#### Verify UART Connection

```bash
ls -l /dev/ttyAMA0
```

Should show device with `crw-rw----` permissions and group `dialout`.

### Network Setup

The Swarm system is configured with a dual-network setup for maximum flexibility:

#### Network Interfaces

| Interface | Mode | IP Address | Purpose |
|---|---|---|---|
| `eth0` | Static IP | `192.168.10.1/24` | Main communication interface |
| `wlan0` | DHCP/AP | Auto/`192.168.10.1` | WiFi client or Access Point |

#### WiFi Auto-Manager

The system includes an automatic WiFi manager that:
1. **Scans** for known WiFi networks on boot
2. **Connects** to the first available known network (client mode)
3. **Falls back** to Access Point mode if no known networks found

#### Access Point Details

When in AP mode:
- **SSID**: `Swarm_AP`
- **Password**: `swarmascend`
- **IP Address**: `192.168.10.1`
- **DHCP Range**: `192.168.10.10 - 192.168.10.50`

#### Connect to the Swarm

**Via Access Point:**
```bash
# Connect your laptop to Swarm_AP WiFi network
# Password: swarmascend

# SSH into the drone
ssh pi@192.168.10.1
```

**Via Ethernet:**
```bash
# Connect ethernet cable to your laptop
# Configure your laptop's ethernet to 192.168.10.x (x != 1)

# SSH into the drone
ssh pi@192.168.10.1
```

#### Add Known WiFi Networks

Edit the known networks file:
```bash
sudo nano /etc/wifi_networks.conf
```

Add networks (one per line):
```
SSID:password
MyHomeWiFi:mypassword123
WorkNetwork:workpassword
```

Restart the WiFi manager service:
```bash
sudo systemctl restart wifi-manager.service
```

#### Network Service Management

```bash
# Check WiFi manager status
sudo systemctl status wifi-manager.service

# View WiFi manager logs
sudo journalctl -u wifi-manager.service -f

# Manually start Access Point
sudo systemctl start hostapd
sudo systemctl start dnsmasq

# Manually stop Access Point
sudo systemctl stop hostapd
sudo systemctl stop dnsmasq

# Check current network status
ip addr show
iwconfig
```

---

## Verification

### Run Verification Script

```bash
cd ~/swarm-ros
./verify_setup.sh
```

The script checks:
- ✓ Ubuntu version
- ✓ ROS2 Humble installation
- ✓ Python dependencies
- ✓ I2C configuration and LiDAR detection
- ✓ UART configuration and FC connection
- ✓ Workspace build status
- ✓ Launch files and configuration

### Manual Hardware Tests

#### Test I2C Communication

```bash
# Scan I2C bus
i2cdetect -y 1

# Read from LiDAR (if using i2c-tools)
i2cget -y 1 0x08 0x24 w
```

#### Test UART Communication

```bash
# Check if device is accessible
ls -l /dev/ttyAMA0

# Monitor serial data (Ctrl+C to exit)
cat /dev/ttyAMA0
```

#### Test ROS2 Nodes

```bash
# Source environment
source /opt/ros/humble/setup.bash
source ~/swarm-ros/install/setup.bash

# List available nodes
ros2 pkg executables swarm_ai_integration

# Test individual node
ros2 run swarm_ai_integration lidar_reader_node
```

---

## Troubleshooting

### ROS2 Issues

**Problem**: `ros2: command not found`

**Solution**:
```bash
source /opt/ros/humble/setup.bash
# Add to ~/.bashrc to make permanent
```

**Problem**: Package not found after building

**Solution**:
```bash
cd ~/swarm-ros
rm -rf build install log
colcon build --symlink-install
source install/setup.bash
```

### I2C Issues

**Problem**: `Could not open file /dev/i2c-1: Permission denied`

**Solution**:
```bash
# Add user to i2c group
sudo usermod -a -G i2c $USER
# Log out and back in
```

**Problem**: No device at address 0x08

**Solution**:
- Check LiDAR is powered on
- Verify wiring (SDA, SCL, VCC, GND)
- Check if I2C is enabled in config.txt
- Try scanning: `i2cdetect -y 1`

### UART Issues

**Problem**: `/dev/ttyAMA0: Permission denied`

**Solution**:
```bash
# Add user to dialout group
sudo usermod -a -G dialout $USER
# Log out and back in
```

**Problem**: UART device not found

**Solution**:
- Check UART is enabled in `/boot/firmware/config.txt`
- Verify physical connection to flight controller
- Try alternative devices: `/dev/ttyUSB0` or `/dev/ttyACM0`
- Update config in `swarm_params.yaml`:
  ```yaml
  fc_comms_node:
    ros__parameters:
      serial_port: "/dev/ttyUSB0"  # Change as needed
  ```

### Build Issues

**Problem**: `Permission denied: 'log/build_XXXX'` when running `colcon build`

**Solution**:
```bash
# Fix ownership of workspace (happens if you ran setup with sudo)
cd ~/swarm-ros
sudo chown -R $USER:$USER ~/swarm-ros

# Clean old build artifacts
rm -rf log build install

# Rebuild
colcon build --symlink-install
```

> **Note**: The latest setup.sh automatically fixes this, but if you encounter it, run the commands above.

**Problem**: CMake or compilation errors

**Solution**:
```bash
# Install missing dependencies
rosdep install --from-paths src --ignore-src -r -y

# Clean and rebuild
cd ~/swarm-ros
rm -rf build install log
colcon build --symlink-install
```

**Problem**: Python import errors

**Solution**:
```bash
# Reinstall system Python dependencies
pip3 install --upgrade numpy scipy pyserial smbus2

# Reinstall AI packages in virtual environment
source ~/ai_flight_node_env/bin/activate
pip install --upgrade pip
pip install -r ~/swarm-ros/ai_model_requirements.txt
deactivate
```

**Problem**: Virtual environment not found or in wrong location (`/root/ai_flight_node_env`)

**Solution**:
```bash
# Remove incorrectly located venv
sudo rm -rf /root/ai_flight_node_env

# Create venv in correct location (as pi user)
python3 -m venv ~/ai_flight_node_env
~/ai_flight_node_env/bin/pip install --upgrade pip
~/ai_flight_node_env/bin/pip install -r ~/swarm-ros/ai_model_requirements.txt
```

> **Note**: The latest setup.sh creates the venv in the correct user's home directory automatically.

### Network Issues

**Problem**: Cannot connect to Swarm_AP WiFi

**Solution**:
```bash
# Check if WiFi manager service is running
sudo systemctl status wifi-manager.service

# Check if hostapd and dnsmasq are running (AP mode)
sudo systemctl status hostapd
sudo systemctl status dnsmasq

# Restart WiFi manager
sudo systemctl restart wifi-manager.service

# Check logs
sudo journalctl -u wifi-manager.service -f
```

**Problem**: WiFi not switching to known network

**Solution**:
```bash
# Verify known networks file exists
cat /etc/wifi_networks.conf

# Check for typos in SSID or password
sudo nano /etc/wifi_networks.conf

# Restart WiFi manager
sudo systemctl restart wifi-manager.service

# Manually scan for networks
nmcli dev wifi list
```

**Problem**: Ethernet connection not working

**Solution**:
```bash
# Check eth0 configuration
ip addr show eth0

# Verify static IP is set to 192.168.10.1
# Should show: inet 192.168.10.1/24

# Check Netplan configuration
cat /etc/netplan/99-swarm-network.yaml

# Reapply Netplan configuration
sudo netplan apply

# Verify your laptop's ethernet is in the same subnet (192.168.10.x)
```

**Problem**: Cannot SSH to 192.168.10.1

**Solution**:
```bash
# Verify you're connected to Swarm_AP or ethernet
# Check your IP address (should be 192.168.10.x)
ip addr

# Ping the drone
ping 192.168.10.1

# Check if SSH is running on the drone
sudo systemctl status ssh

# Try connecting with verbose output
ssh -vvv pi@192.168.10.1
```

### Runtime Issues

**Problem**: Nodes crash on startup

**Solution**:
- Check logs: `ros2 topic echo /rosout`
- Verify hardware is connected
- Check configuration in `config/swarm_params.yaml`
- Run verification: `./verify_setup.sh`

**Problem**: No GPS fix

**Solution**:
- Move to open sky location
- Wait 30-60 seconds for GPS lock
- Check GPS satellites: `ros2 topic echo /fc/gps_satellites`
- Verify HDOP: `ros2 topic echo /fc/gps_hdop`

---

## Configuration Files

### Main Configuration

**Location**: `src/swarm_ai_integration/config/swarm_params.yaml`

Key parameters to configure:
- Flight controller serial port
- LiDAR I2C address
- Safety limits (altitude, velocity, battery)
- AI model path

### Launch Configuration

**Location**: `src/swarm_ai_integration/launch/swarm_ai_launch.py`

Modify to enable/disable nodes as needed.

---

## Process Management with PM2

PM2 is **installed by default** by the setup script and provides powerful process management features.

### Quick Start

```bash
# Start the ROS system with PM2
./launch.sh

# Check status
pm2 list
```

### Common PM2 Commands

```bash
# View logs in real-time (all processes)
pm2 logs

# View logs for specific process
pm2 logs swarm-ros-launched

# Monitor resource usage (CPU, memory)
pm2 monit

# Stop the system
pm2 stop swarm-ros-launched

# Restart the system
pm2 restart swarm-ros-launched

# Stop all PM2 processes
pm2 stop all

# Restart all PM2 processes
pm2 restart all

# Delete process from PM2
pm2 delete swarm-ros-launched

# Show detailed process info
pm2 show swarm-ros-launched
```

### Auto-Start on Boot

PM2 is **automatically configured** to start on boot by the setup script:

```bash
# Verify startup configuration
pm2 startup

# Save current process list (auto-start this on boot)
pm2 save

# List saved processes
pm2 list
```

After running `pm2 save`, your ROS system will automatically start when the Raspberry Pi boots!

### Disable Auto-Start

If you don't want auto-start:

```bash
# Remove from startup
pm2 unstartup systemd

# Or delete specific process
pm2 delete swarm-ros-launched
pm2 save
```

### PM2 Log Files

PM2 stores logs in `~/.pm2/logs/`:

```bash
# View log file locations
ls -la ~/.pm2/logs/

# Tail error logs
tail -f ~/.pm2/logs/swarm-ros-launched-error.log

# Tail output logs
tail -f ~/.pm2/logs/swarm-ros-launched-out.log

# Clear all logs
pm2 flush
```

### Advanced PM2 Features

```bash
# Restart on file changes (development)
pm2 start launch.sh --watch

# Set environment variables
pm2 start launch.sh --name swarm-ai --env production

# Limit memory and restart on threshold
pm2 start launch.sh --max-memory-restart 1G

# Run multiple instances (if needed)
pm2 scale swarm-ros-launched 2
```

---

## Safety Checklist

Before first flight:

- [ ] All hardware connections verified
- [ ] GPS has good fix (6+ satellites, HDOP < 2.0)
- [ ] LiDAR reading correctly
- [ ] Battery voltage correct
- [ ] Flight controller armed successfully
- [ ] Safety monitor active
- [ ] Home position set correctly
- [ ] Custom RTH tested in simulation
- [ ] Emergency stop procedure understood

---

## Support

For issues or questions:
- Check logs: `ros2 topic echo /rosout`
- Run diagnostics: `./verify_setup.sh`
- Review safety status: `ros2 topic echo /safety/status`
- Check flight logs: `flight-logs/` directory

---

## Next Steps

After successful setup:

1. **Configure Parameters**: Edit `config/swarm_params.yaml` for your hardware
2. **Test in Simulation**: Use AI adapter simulator nodes
3. **Calibrate Sensors**: Ensure GPS, IMU, and LiDAR are accurate
4. **Load AI Model**: Place trained model in configured path
5. **Ground Test**: Test with props off, verify all nodes working
6. **First Flight**: Test custom RTH and landing in safe environment

---

## Summary of Recent Improvements

### Setup Script Enhancements (2024-11-16)

The `setup.sh` script now includes:

✅ **Automatic Network Configuration**
- Configures WiFi Access Point with automatic fallback
- Sets up static IP on ethernet (192.168.10.1/24)
- Automatic WiFi manager for known networks
- Easy SSH access to drone via WiFi or ethernet
- AP credentials: SSID=`Swarm_AP`, Password=`swarmascend`

✅ **Automatic Permission Fixes**
- Fixes workspace ownership if run with sudo
- Prevents `colcon build` permission errors
- Cleans old build artifacts automatically

✅ **Python venv in Correct Location**
- Creates venv in user's home directory (not `/root/`)
- Properly handles sudo vs normal user execution
- Ensures all packages installed with correct ownership

✅ **PM2 Installed by Default**
- Process management for auto-restart
- Survives system reboots
- Centralized logging
- Use `--skip-pm2` to disable

✅ **Smart User Detection**
- Correctly identifies actual user even when run with sudo
- Sets ownership appropriately
- No more manual permission fixes needed

### Network Setup Features (2024-11-16)

The `network_setup.sh` script provides:

✅ **Dual Network Interface**
- `eth0`: Static IP at 192.168.10.1/24 (always available)
- `wlan0`: Dynamic mode (client or AP)

✅ **Intelligent WiFi Manager**
- Automatically tries to connect to known WiFi networks
- Falls back to Access Point if no known network found
- Systemd service runs on boot
- Easy to add new known networks

✅ **Access Point Mode**
- Automatic DHCP server (range: 192.168.10.10-50)
- Pre-configured with sensible defaults
- Easy to customize (SSID, password, IP range)

✅ **Remote Access**
- SSH via WiFi AP or ethernet
- Consistent IP address (192.168.10.1)
- No need for monitor/keyboard after setup

---

**Last Updated**: 2024-11-16

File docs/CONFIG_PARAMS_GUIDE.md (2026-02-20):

# ROS2 Parameter Configuration Guide

Comprehensive guide to all configurable parameters in the Swarm AI Integration system.

> 📖 **Deep Dive:** For context on how these parameters fit into the overall system architecture, see:
> - [Chapter 3: From Data to Motion](https://substack.com/home/post/p-177453660) — Software architecture and data flow
> - [Chapter 3.5: Additional Configurations](https://substack.com/home/post/p-180586067) — Advanced configuration and tuning

---

## Table of Contents

1. [Introduction](#introduction)
2. [Parameter File Location](#parameter-file-location)
3. [AI Adapter Node](#ai-adapter-node)
4. [AI Flight Node](#ai-flight-node)
5. [Safety Monitor Node](#safety-monitor-node)
6. [FC Communications Node](#fc-communications-node)
7. [FC Adapter Node](#fc-adapter-node)
8. [Black Box Recorder Node](#black-box-recorder-node)
9. [LiDAR Reader Node](#lidar-reader-node)
10. [Using Parameters](#using-parameters)
11. [Tuning Guide](#tuning-guide)
12. [Troubleshooting](#troubleshooting)

---

## Introduction

All configurable parameters for the Swarm AI Integration system are centralized in the `swarm_params.yaml` file. This guide explains each parameter, its purpose, valid ranges, and tuning recommendations.

---

## Parameter File Location

**Default path:**
```
~/swarm-ros/src/swarm_ai_integration/config/swarm_params.yaml
```

**Installation path (after build):**
```
~/swarm-ros/install/swarm_ai_integration/share/swarm_ai_integration/config/swarm_params.yaml
```

---

## AI Adapter Node

**Node name:** `ai_adapter_node`

**Purpose:** Transforms raw sensor data into observation vectors for the AI model.

### 131-D Observation Array Structure

The AI Adapter Node produces a 131-dimensional observation array that matches the PyBullet training environment format:

| Index | Size | Component | Description | Units |
|---|---|---|---|---|
| 0-2 | 3 | **Position ENU** | Relative position from start point | meters [E, N, U] |
| 3-5 | 3 | **Orientation** | Euler angles | radians [roll, pitch, yaw] |
| 6-8 | 3 | **Velocity** | Linear velocity in ENU frame | m/s [vE, vN, vU] |
| 9-11 | 3 | **Angular Velocity** | Rotational velocity | rad/s [wx, wy, wz] |
| 12-111 | 100 | **Action Buffer** | History of 25 past actions (25 × 4) | normalized [-1, 1] |
| 112-127 | 16 | **LiDAR Distances** | Normalized ray distances | normalized [0, 1] |
| 128-130 | 3 | **Goal Vector** | Direction to goal in ENU | normalized by max_ray_distance |

**Total: 131 elements**

#### Component Details

- **Position ENU [0:3]**: Drone position relative to the starting point, in East-North-Up coordinates
- **Orientation [3:6]**: Roll, pitch, yaw angles from the IMU in radians
- **Velocity [6:9]**: Ground speed decomposed into ENU components from GPS
- **Angular Velocity [9:12]**: Gyroscope readings in rad/s
- **Action Buffer [12:112]**: Rolling buffer of the last 25 actions (each action is 4 values: thrust + 3-axis rotation), enabling the model to understand recent control history
- **LiDAR [112:128]**: 16 distance rays normalized by `max_ray_distance` (0 = at sensor, 1 = max range)
- **Goal Vector [128:131]**: Vector from current position to goal, scaled by `max_ray_distance`

### Parameters

#### Observation Generation

##### `telemetry_rate`
```yaml
telemetry_rate: 30.0  # Hz
```

**Description:** Rate at which observations are generated and published to the AI model.

**Range:** 1.0 - 100.0 Hz

**Tuning:**
- **Higher (30-50 Hz):** More responsive AI, smoother control, higher CPU usage
- **Lower (10-20 Hz):** Less CPU usage, slightly delayed reactions
- **Recommendation:** 30 Hz provides good balance for most applications

**Impact:** Directly affects AI reaction time and control loop stability.

---

##### `max_ray_distance`
```yaml
max_ray_distance: 20.0  # meters
```

**Description:** Maximum distance used for normalizing LiDAR observations.

**Range:** 5.0 - 50.0 meters

**CRITICAL:** Must match the value used during AI model training!

**Tuning:**
- Value should match training environment
- Affects how distance observations are scaled (0-1)
- Incorrect value will cause AI to misinterpret distances

**Impact:** Incorrect value will cause AI to make poor decisions.

---

##### `action_buffer_size`
```yaml
action_buffer_size: 25  # past actions
```

**Description:** Number of past AI actions to buffer and include in observations.

**Range:** 0 - 100

**Tuning:**
- **Larger (25-50):** AI has more historical context, uses more memory
- **Smaller (10-20):** Less memory, less historical awareness
- **Zero (0):** No action history (not recommended for trained models expecting it)

**Impact:** Must match model training configuration. Affects memory usage.

---

#### Initial Position

##### `relative_start_enu`
```yaml
relative_start_enu: [0.0, 0.0, 3.0]  # [East, North, Up] meters
```

**Description:** Initial relative position in ENU (East-North-Up) frame. Our models were trained with [ 0.0, 0.0, 3.0] as starting point.

**Format:** `[east, north, up]` in meters

**Tuning:**
- **East:** Positive = east, negative = west
- **North:** Positive = north, negative = south
- **Up:** Altitude offset (typically 3.0 meters for takeoff)

**Common values:**
- `[0.0, 0.0, 3.0]` - Start at origin, 3m altitude
- `[5.0, 0.0, 2.0]` - Start 5m east, 2m altitude

---

#### GPS Settings

##### `min_gps_satellites`
```yaml
min_gps_satellites: 5  # satellites
```

**Description:** Minimum number of GPS satellites required for valid GPS fix.

**Range:** 4 - 12

**Tuning:**
- **Lower (4-5):** Works in obstructed areas, less accuracy
- **Higher (6-8):** Better accuracy, may not work indoors/urban
- **Recommendation:** 5 for most scenarios, 6-7 for open sky

**Impact:** Affects when GPS-dependent modes can engage.

---

#### QoS Settings

##### `sensor_qos_depth`
```yaml
sensor_qos_depth: 1  # messages
```

**Description:** Queue depth for sensor topics (best-effort QoS).

**Range:** 1 - 10

**Tuning:**
- **1:** Latest data only (recommended for sensors)
- **5-10:** Buffer multiple messages (if processing is slow)

---

##### `reliable_qos_depth`
```yaml
reliable_qos_depth: 10  # messages
```

**Description:** Queue depth for reliable topics (commands, configuration).

**Range:** 1 - 100

**Tuning:**
- **10:** Default, handles most cases
- **20-50:** For high-rate command topics

---

## AI Flight Node

**Node name:** `ai_flight_node`

**Purpose:** Runs the trained AI model and generates flight commands.

### Parameters

#### Model Settings

##### `model_path`
```yaml
model_path: "/home/pi/swarm-ros/model/UID_3.zip"
```

**Description:** Absolute path to the trained AI model file (.zip format).

**Format:** String, absolute path

**Common paths:**
- `/home/pi/swarm-ros/model/UID_3.zip` - Development model
- `/opt/swarm/model/production.zip` - Production model
- `~/swarm-ros/model/latest.zip` - Latest trained model

**Troubleshooting:**
- File must exist and be readable
- Must be a valid stable-baselines3 model
- Check path with: `ls -lh /path/to/model.zip`

---

##### `device`
```yaml
device: "cpu"
```

**Description:** Computation device for PyTorch inference.

**Values:**
- `"cpu"` - CPU inference (Raspberry Pi, most systems)
- `"cuda"` - GPU inference (if NVIDIA GPU available)
- `"cuda:0"` - Specific GPU device

**Tuning:**
- Raspberry Pi: Use `"cpu"` only
- Jetson Nano/Xavier: Can use `"cuda"`
- Desktop with GPU: Use `"cuda"` for faster inference

**Disclaimer:** Other modes besides CPU have not yet been tested, and this parameter is intended for future implementations.

---

#### Prediction Settings

##### `prediction_rate`
```yaml
prediction_rate: 10.0  # Hz
```

**Description:** Rate at which AI model makes predictions.

**Range:** 1.0 - 50.0 Hz

**Tuning:**
- **Higher (20-30 Hz):** Faster reactions, higher CPU usage
- **Lower (5-10 Hz):** Lower CPU, slightly delayed reactions
- **Recommendation:** 10 Hz is sufficient for most flight tasks

**Impact:** Affects CPU usage and AI responsiveness. Should be ≤ `telemetry_rate`.

---

#### QoS Settings

##### `qos_depth`
```yaml
qos_depth: 1  # messages
```

**Description:** Queue depth for AI topics (observations and actions).

**Range:** 1 - 10

**Tuning:**
- **1:** Latest data only (recommended)
- **5:** Buffer if AI inference is slow

---

## Safety Monitor Node

**Node name:** `safety_monitor_node`

**Purpose:** Monitors flight parameters and enforces safety limits.

### Parameters

#### Attitude Limits

##### `max_roll_angle`
```yaml
max_roll_angle: 15.0  # degrees
```

**Description:** Maximum allowed roll angle before safety intervention.

**Range:** 5.0 - 45.0 degrees

**Tuning:**
- **Conservative (10-15°):** Safer, limits aggressive maneuvers
- **Aggressive (20-30°):** Allows faster movement, less stable
- **Recommendation:** 15° for autonomous flight

**Safety:** Exceeding this triggers safety override.

---

##### `max_pitch_angle`
```yaml
max_pitch_angle: 15.0  # degrees
```

**Description:** Maximum allowed pitch angle before safety intervention.

**Range:** 5.0 - 45.0 degrees

**Tuning:** Same as `max_roll_angle`

---

#### Altitude Limits

##### `min_altitude`
```yaml
min_altitude: 0.0  # meters
```

**Description:** Minimum allowed altitude (AGL).

**Range:** 0.0 - 10.0 meters

**Tuning:**
- **0.0:** No minimum altitude check (default)
- **1.0-2.0:** Prevents landing during flight
- **Higher:** Use for specific mission requirements

**Note:** Currently not actively used for safety triggers, reserved for future implementations.

---

##### `max_altitude`
```yaml
max_altitude: 10.0  # meters
```

**Description:** Maximum allowed altitude (AGL).

**Range:** 5.0 - 120.0 meters

**Tuning:**
- **Low (5-10m):** Indoor/testing, safer
- **Medium (20-30m):** Outdoor flight
- **High (50-100m):** Advanced operations
- **Legal limit:** Check local regulations (often 120m/400ft)

**Safety:** Exceeding triggers automatic descent.

---

#### Geofencing

##### `max_distance_from_home`
```yaml
max_distance_from_home: 50.0  # meters
```

**Description:** Maximum horizontal distance from takeoff point.

**Range:** 10.0 - 1000.0 meters

**Tuning:**
- **Small (20-50m):** Testing, confined spaces
- **Medium (100-200m):** Normal operations
- **Large (500+m):** Long-range missions

**Safety:** Exceeding triggers RTH (Return to Home).

---

#### Safety Actions

##### `hover_duration`
```yaml
hover_duration: 3.0  # seconds
```

**Description:** How long to hover before initiating landing after safety event.

**Range:** 0.0 - 10.0 seconds

**Tuning:**
- **0:** Immediate landing (aggressive)
- **3-5:** Gives time for operator intervention
- **10:** Maximum delay before landing

---

#### System Configuration

##### `monitor_rate`
```yaml
monitor_rate: 20.0  # Hz
```

**Description:** Rate at which safety checks are performed.

**Range:** 5.0 - 50.0 Hz

**Tuning:**
- **Higher (20-30 Hz):** Faster safety response, more CPU
- **Lower (10-15 Hz):** Less CPU, slightly delayed safety checks
- **Recommendation:** 20 Hz for good safety response

---

##### `qos_depth`
```yaml
qos_depth: 1  # messages
```

**Description:** Queue depth for safety topics.

**Range:** 1 - 10

---

## FC Communications Node

**Node name:** `fc_comms_node`

**Purpose:** Communicates with INAV flight controller via MSP serial protocol.

### Parameters

#### Serial Communication

##### `serial_port`
```yaml
serial_port: "/dev/ttyAMA0"
```

**Description:** Serial port device for INAV communication.

**Common values:**
- `/dev/ttyAMA0` - Raspberry Pi hardware UART
- `/dev/ttyUSB0` - USB serial adapter
- `/dev/ttyACM0` - Some flight controllers

**Verification:**
```bash
ls -l /dev/ttyAMA0
```

---

##### `baud_rate`
```yaml
baud_rate: 115200
```

**Description:** Serial communication baud rate.

**Values:** Must match INAV MSP baud rate (typically 115200)

**Common values:** 9600, 57600, 115200

---

##### `timeout`
```yaml
timeout: 1.0  # seconds
```

**Description:** Serial read timeout.

**Range:** 0.1 - 5.0 seconds

**Tuning:**
- **Lower (0.5-1.0):** Faster timeout detection
- **Higher (2.0-3.0):** More tolerant of slow responses

---

##### `max_rx_buffer_size`
```yaml
max_rx_buffer_size: 1024  # bytes
```

**Description:** Maximum receive buffer size.

**Range:** 256 - 4096 bytes

**Tuning:** 1024 is sufficient for standard MSP messages.

---

#### Connection Management

##### `reconnect_interval`
```yaml
reconnect_interval: 5.0  # seconds
```

**Description:** Time between reconnection attempts after connection loss.

**Range:** 1.0 - 30.0 seconds

---

##### `telemetry_rate`
```yaml
telemetry_rate: 10.0  # Hz
```

**Description:** Rate at which telemetry data is requested from FC.

**Range:** 1.0 - 50.0 Hz

**Tuning:**
- **Higher (20-30 Hz):** More frequent updates, higher bus load
- **Lower (5-10 Hz):** Less load, slightly delayed data
- **Recommendation:** 10 Hz for stable telemetry

---

##### `heartbeat_rate`
```yaml
heartbeat_rate: 1.0  # Hz
```

**Description:** Rate of heartbeat checks to FC.

**Range:** 0.5 - 10.0 Hz

---

##### `heartbeat_timeout`
```yaml
heartbeat_timeout: 10.0  # seconds
```

**Description:** Time without heartbeat before declaring connection dead.

**Range:** 3.0 - 30.0 seconds

---

##### `connection_timeout`
```yaml
connection_timeout: 10.0  # seconds
```

**Description:** Overall connection timeout.

**Range:** 5.0 - 60.0 seconds

---

#### Waypoint Polling

##### `waypoint_poll_mode`
```yaml
waypoint_poll_mode: "first"
```

**Description:** How to poll waypoints from FC.

**Values:**
- `"first"` - Poll only first waypoint
- `"all"` - Poll all waypoints up to max_waypoint_cycle
- `"none"` - Don't poll waypoints

---

##### `max_waypoint_cycle`
```yaml
max_waypoint_cycle: 10
```

**Description:** Maximum waypoint index to cycle through (if poll mode is "all").

**Range:** 1 - 60

---

#### Data Processing Scales

##### `imu_scale_accel`
```yaml
imu_scale_accel: 0.01916015625  # 9.81/512.0
```

**Description:** IMU accelerometer scale factor.

**Note:** This is defined by INAV firmware, do not change unless you know what you're doing.

---

##### `imu_scale_gyro`
```yaml
imu_scale_gyro: 0.001
```

**Description:** IMU gyroscope scale factor.

**Note:** Defined by INAV firmware.

---

##### `battery_voltage_scale`
```yaml
battery_voltage_scale: 10.0
```

**Description:** Battery voltage divisor (INAV reports voltage * 10).

**Note:** Defined by INAV protocol.

---

##### `battery_current_scale`
```yaml
battery_current_scale: 100.0
```

**Description:** Battery current divisor (INAV reports amperage * 100).

**Note:** Defined by INAV protocol.

---

#### QoS Settings

##### `command_qos_depth`
```yaml
command_qos_depth: 10  # messages
```

**Description:** Queue depth for command topics.

**Range:** 1 - 50

---

#### GPS Altitude Fallback

##### `gps_altitude_timeout`
```yaml
gps_altitude_timeout: 5.0  # seconds
```

**Description:** How long GPS altitude data remains valid for use as barometer fallback.

**Range:** 1.0 - 30.0 seconds

**Purpose:** When barometer is unavailable or invalid, GPS altitude is used as fallback if it was received within this timeout period.

**Tuning:**
- **Short (2-5s):** Only use very recent GPS data
- **Long (10-30s):** Allow older GPS data as fallback

**Note:** GPS altitude is less accurate than barometer but provides backup when barometer fails.

---

## FC Adapter Node

**Node name:** `fc_adapter_node`

**Purpose:** Converts AI action vectors to RC values for the flight controller. Roll and pitch use a normalization-based joystick-style mapping; throttle is controlled by a LiDAR-based altitude hold controller (AI `vz` is ignored).

### Action Vector Mapping

The AI publishes `[vx, vy, vz, speed]` action vectors. The node maps **roll/pitch** using normalization and delegates **throttle** to the altitude hold controller:

**Roll & Pitch:**
1. Find the max absolute component in `(vx, vy)` (vz is not used)
2. Normalize each component by this max value (so the dominant axis reaches ±1)
3. Scale by `speed` (0-1)
4. Map to RC range: `-1 → rc_min`, `0 → rc_mid`, `+1 → rc_max`

**Throttle (altitude hold):**
- A bang-bang controller reads the downward LiDAR (`/lidar_distance`) and compares against `target_altitude_m ± 0.5m`
- Below band → throttle 1600 (climb), above band → throttle 1400 (descend), in band → throttle 1500 (neutral)
- If no fresh LiDAR data, throttle defaults to 1500

**Examples:**
- `(1, -1, 0, 1)` → roll=1800, pitch=1200, throttle=altitude-hold value

### Parameters

#### Control Rate

##### `control_rate_hz`
```yaml
control_rate_hz: 40.0  # Hz
```

**Description:** Main control loop rate.

**Range:** 10.0 - 100.0 Hz

**Tuning:**
- **Higher (40-50 Hz):** Tighter control, more CPU usage
- **Lower (20-30 Hz):** Less CPU, slightly less responsive
- **Recommendation:** 40 Hz for good control with reasonable CPU usage

**Impact:** Directly affects control loop responsiveness.

---

#### Command Processing

##### `command_timeout`
```yaml
command_timeout: 1.0  # seconds
```

**Description:** Time without AI commands before switching to hover mode.

**Range:** 0.5 - 5.0 seconds

**Tuning:**
- **Short (0.5-1.0s):** Quick safety response, may trigger on network hiccups
- **Long (2.0-3.0s):** More tolerant, slower safety response

---

#### Startup Sequence Timing

##### `warmup_duration_sec`
```yaml
warmup_duration_sec: 10.0  # seconds
```

**Description:** Total warmup duration before AI control begins.

**Range:** 5.0 - 30.0 seconds

**Purpose:** Overall warmup period that allows the flight controller to stabilize before AI takes control.

**Tuning:**
- **Shorter (5-10s):** Faster startup, less stabilization time
- **Longer (15-30s):** More time for GPS lock and FC stabilization

---

##### `arming_duration_sec`
```yaml
arming_duration_sec: 20.0  # seconds
```

**Description:** Duration of the arming phase with ARM channel high and throttle at minimum.

**Range:** 5.0 - 60.0 seconds

**Purpose:** Time for the flight controller to complete arming sequence, initialize sensors, and acquire GPS lock.

**Tuning:**
- **Shorter (10-15s):** Quick startup, may miss GPS lock
- **Longer (20-30s):** More time for GPS satellites and sensor initialization
- **Recommendation:** 20 seconds provides good balance for outdoor flights

**Startup Sequence:** Phase 0 (Arming) → Phase 1 (Rise, LiDAR-guided: 0.5 s burst at 1600, then 0.5 s ticks until target altitude band is reached) → Phase 2 (Yaw Alignment) → Phase 3 (AI Control)

---

#### RC Channel Settings

##### `rc_mid_value`
```yaml
rc_mid_value: 1500
```

**Description:** RC channel center value (neutral position).

**Standard:** 1500 (1000-2000 range)

**Note:** This is the standard RC midpoint. Do not change unless your FC is configured differently.

---

##### `rc_min_value`
```yaml
rc_min_value: 1200
```

**Description:** Minimum RC value output for roll/pitch.

**Range:** 1000 - 1500

**Purpose:** Limits how far below center the RC values can go.

**Calculation:** With `rc_mid_value: 1500` and `rc_min_value: 1200`, maximum negative deflection is 300 RC units.

---

##### `rc_max_value`
```yaml
rc_max_value: 1800
```

**Description:** Maximum RC value output for roll/pitch.

**Range:** 1500 - 2000

**Purpose:** Limits how far above center the RC values can go.

**Calculation:** With `rc_mid_value: 1500` and `rc_max_value: 1800`, maximum positive deflection is 300 RC units.

**IMPORTANT:** The range between `rc_min_value` and `rc_max_value` determines the maximum tilt the drone can achieve. The `half_range` (rc_max - rc_mid = 300) is the maximum RC deflection for roll/pitch. Throttle is independently controlled by the altitude hold controller.

---

#### Altitude Hold

##### `target_altitude_m`
```yaml
target_altitude_m: 3.0  # meters
```

**Description:** Target altitude for the LiDAR-based altitude hold controller.

**Range:** 1.0 - 10.0 meters

**Purpose:** The altitude hold controller uses a bang-bang approach: if LiDAR altitude is below `target - 0.5m` it sends throttle up (1600), above `target + 0.5m` it sends throttle down (1400), and within the band it sends neutral throttle (1500).

**Tuning:**
- **Low (2.0-3.0m):** Close to ground, good for testing
- **High (4.0-6.0m):** Higher operating altitude, needs reliable LiDAR readings

**Note:** Requires the downward LiDAR sensor to be active and publishing on `/lidar_distance`.

---

#### Speed Multiplier

##### `speed_multiplier`
```yaml
speed_multiplier: 2.0
```

**Description:** Scales the AI model's speed output before it is used to compute roll/pitch RC deflection.

**Range:** 0.5 - 4.0 (output is clamped to 1.0 so it can never exceed RC limits)

**Purpose:** The AI model typically outputs speed values in the range 0.10–0.33. Without amplification, the effective RC deflection is small (e.g. `0.18 × 300 ≈ 54 units`). A multiplier of 2.0 doubles it to `~108 units`, making the drone move noticeably faster toward its target.

**Calculation:** `effective_speed = min(1.0, ai_speed × speed_multiplier)` → used to scale roll/pitch RC deviation.

**Tuning:**
- **1.0:** No amplification — useful to observe raw AI behavior
- **2.0 (default):** Recommended starting point; doubles effective deflection
- **3.0–4.0:** Aggressive movement; verify stability before using outdoors

**Note:** This only affects roll and pitch (lateral movement). Throttle is independently managed by the altitude hold controller.

---

### Tuning the RC Range

The roll/pitch sensitivity is determined by `rc_min_value` and `rc_max_value`. Throttle is independently managed by the altitude hold controller using LiDAR.

1. **Default (flight-tested):**
   ```yaml
   rc_min_value: 1200
   rc_max_value: 1800
   ```

2. **Conservative (for initial testing):**
   ```yaml
   rc_min_value: 1400
   rc_max_value: 1600
   ```

3. **Narrow range** reduces roll/pitch authority; **wider range** gives more aggressive movement.

---

## Black Box Recorder Node

**Node name:** `black_box_recorder_node`

**Purpose:** Records all flight data to CSV files for post-flight analysis.

### Parameters

#### Storage Settings

##### `log_directory`
```yaml
log_directory: "~/swarm-ros/flight-logs"
```

**Description:** Directory where flight log files are saved.

**Format:** String, supports `~` expansion

**Common values:**
- `~/swarm-ros/flight-logs` - Default location
- `/var/log/swarm_blackbox` - System log location
- `/mnt/usb/logs` - External storage

**Note:** Directory will be created if it doesn't exist.

---

##### `max_log_file_size_mb`
```yaml
max_log_file_size_mb: 100  # MB
```

**Description:** Maximum log file size before rotation.

**Range:** 10 - 1000 MB

**Tuning:**
- **Small (10-50 MB):** More files, easier to manage
- **Large (100-500 MB):** Fewer files, longer flights per file

---

#### Logging Behavior

##### `log_rate_hz`
```yaml
log_rate_hz: 10.0  # Hz
```

**Description:** Frequency of snapshot logging.

**Range:** 1.0 - 100.0 Hz

**Tuning:**
- **Lower (5-10 Hz):** Smaller log files, less detail
- **Higher (20-50 Hz):** Larger files, more detail
- **Recommendation:** 10 Hz captures sufficient detail

**Impact:** Higher rates create larger log files.

---

#### QoS Settings

##### `reliable_qos_depth`
```yaml
reliable_qos_depth: 10  # messages
```

**Description:** Queue depth for reliable data logging.

**Range:** 1 - 50

---

##### `sensor_qos_depth`
```yaml
sensor_qos_depth: 1  # messages
```

**Description:** Queue depth for sensor data logging.

**Range:** 1 - 10

---

## LiDAR Reader Node

**Node name:** `down_lidar/lidar_reader_down` (for downward-facing sensor)

**Purpose:** Reads distance measurements from DFRobot dTOF SEN0684 LiDAR sensor via I2C.

### Parameters

#### I2C Communication

##### `i2c_bus`
```yaml
i2c_bus: 1
```

**Description:** I2C bus number.

**Common values:**
- Raspberry Pi: 1 (default)
- Some platforms: 0 or 2

**Verify:**
```bash
i2cdetect -l
```

---

##### `i2c_address`
```yaml
i2c_address: 0x08
```

**Description:** I2C device address of the LiDAR sensor.

**Format:** Hexadecimal (0x00 - 0x7F)

**Common values:**
- dTOF SEN0684 default: 0x29
- Custom address: 0x08 (as configured in your system)

**Verify:**
```bash
i2cdetect -y 1
# Should show device at configured address
```

---

##### `distance_register`
```yaml
distance_register: 0x24
```

**Description:** Register address for reading distance data.

**Note:** Sensor-specific, typically 0x24 for dTOF SEN0684 custom firmware.

---

#### Sensor Configuration

##### `frame_id`
```yaml
frame_id: "down_lidar_link"
```

**Description:** TF frame ID for this sensor.

**Purpose:** Used for coordinate transformations in ROS.

**Format:** String, valid TF frame name

---

##### `sensor_position`
```yaml
sensor_position: "down"
```

**Description:** Mounting position description.

**Values:** `"down"`, `"front"`, `"back"`, etc.

**Purpose:** Helps identify which sensor in multi-sensor setups.

---

##### `publish_rate`
```yaml
publish_rate: 100.0  # Hz
```

**Description:** Publishing rate for distance measurements.

**Range:** 1.0 - 100.0 Hz

**Tuning:**
- **Maximum:** 100 Hz (sensor hardware limit)
- **Recommended:** 50-100 Hz for responsive obstacle detection
- **Lower:** 20-50 Hz for reduced CPU usage

---

#### Range Limits

##### `max_range`
```yaml
max_range: 50.0  # meters
```

**Description:** Maximum valid measurement range. This value is normalized (0 to 1) to the maximum range used in model training (20 m). Any value above this range is considered 1.

**Range:** 1.0 - 50.0 meters

**Note:** dTOF SEN0684 typical max range is ~35m in good conditions, 50m is theoretical max.

---

##### `min_range`
```yaml
min_range: 0.05  # meters
```

**Description:** Minimum valid measurement range.

**Range:** 0.0 - 1.0 meters

**Note:** dTOF SEN0684 minimum is typically ~5cm.

---

##### `field_of_view`
```yaml
field_of_view: 0.035  # radians
```

**Description:** Sensor field of view cone angle.

**Value:** ~2 degrees for dTOF SEN0684

**Note:** Used for visualization and obstacle detection algorithms.

---

#### Data Processing

##### `enable_filtering`
```yaml
enable_filtering: true
```

**Description:** Enable moving average filtering on distance readings.

**Values:** `true` / `false`

**Recommendation:** `true` to reduce noise and false readings.

---

##### `filter_window_size`
```yaml
filter_window_size: 5  # samples
```

**Description:** Moving average filter window size.

**Range:** 1 - 20

**Tuning:**
- **Small (3-5):** Less lag, less smoothing
- **Medium (5-10):** Balanced
- **Large (10-20):** Heavily smoothed, more lag

---

##### `max_invalid_readings`
```yaml
max_invalid_readings: 10  # consecutive readings
```

**Description:** Maximum consecutive invalid readings before reporting sensor error.

**Range:** 5 - 50

**Purpose:** Distinguishes temporary noise from actual sensor failure.

---

#### Timing

##### `status_publish_interval`
```yaml
status_publish_interval: 1.0  # seconds
```

**Description:** How often to publish sensor status messages.

**Range:** 0.5 - 10.0 seconds

---

##### `reconnect_interval`
```yaml
reconnect_interval: 5.0  # seconds
```

**Description:** Time between I2C reconnection attempts after sensor loss.

**Range:** 1.0 - 30.0 seconds

---

#### QoS Settings

##### `sensor_qos_depth`
```yaml
sensor_qos_depth: 1  # messages
```

**Description:** Queue depth for distance measurements.

**Range:** 1 - 10

**Recommendation:** 1 for latest reading only.

---

##### `reliable_qos_depth`
```yaml
reliable_qos_depth: 10  # messages
```

**Description:** Queue depth for status messages.

**Range:** 1 - 50

---

#### Conversion

##### `mm_to_m_divisor`
```yaml
mm_to_m_divisor: 1000.0
```

**Description:** Conversion factor from millimeters to meters.

**Value:** 1000.0 (standard conversion)

**Note:** Do not change unless sensor reports in different units.

## Using Parameters

### Loading from File

Parameters are automatically loaded by the launch file:

```bash
ros2 launch swarm_ai_integration swarm_ai_launch.py
```

### Override at Launch

Override individual parameters:

```bash
ros2 launch swarm_ai_integration swarm_ai_launch.py \
  fc_adapter_node.rc_max_value:=1600 \
  fc_adapter_node.rc_min_value:=1400
```

### Use Custom Config File

```bash
ros2 launch swarm_ai_integration swarm_ai_launch.py \
  params_file:=/path/to/custom_params.yaml
```

### Runtime Parameter Changes

**List parameters:**
```bash
ros2 param list /fc_adapter_node
```

**Get parameter value:**
```bash
ros2 param get /fc_adapter_node rc_max_value
```

**Set parameter value:**
```bash
ros2 param set /fc_adapter_node rc_max_value 1600
```

**Dump all parameters:**
```bash
ros2 param dump /fc_adapter_node > fc_adapter_backup.yaml
```

**Load parameters:**
```bash
ros2 param load /fc_adapter_node fc_adapter_backup.yaml
```

## Tuning Guide

### Initial Testing Configuration

Start with conservative values for first flights:

```yaml
fc_adapter_node:
  ros__parameters:
    rc_min_value: 1200         # RC range (300 units deflection for roll/pitch)
    rc_max_value: 1800         # RC range (300 units deflection for roll/pitch)
    target_altitude_m: 3.0     # LiDAR altitude hold target
    speed_multiplier: 2.0      # Amplify AI speed output (1.0 = no amplification)
    warmup_duration_sec: 10.0  # Good stabilization time
    arming_duration_sec: 20.0  # Time for GPS lock

safety_monitor_node:
  ros__parameters:
    max_altitude: 5.0          # Low altitude
    max_distance_from_home: 20.0  # Close to home
```

### Progressive Tuning Steps

1. **Test hover and altitude hold** - verify LiDAR altitude hold keeps drone at target
2. **Verify stability** - drone should hold position without oscillations
3. **Tune movement speed** - increase `speed_multiplier` if motion is too slow; decrease if twitchy
4. **Adjust RC range** if roll/pitch response still needs tuning (try 1400-1600 for conservative)
5. **Expand safety limits** (altitude, distance as needed)

### Common Tuning Scenarios

#### Drone movement is too slow
- Increase `speed_multiplier` (primary lever — doubles or triples effective RC deflection without changing limits)
- Alternatively, increase `rc_max_value` / decrease `rc_min_value` to widen the roll/pitch range

#### Drone overshoots or feels twitchy
- Narrow the RC range (`rc_min_value: 1400`, `rc_max_value: 1600`)

#### Altitude is unstable
- Verify LiDAR is publishing on `/lidar_distance`
- Adjust `target_altitude_m` if needed
- The altitude hold uses a ±0.5m deadband around the target

#### Drone drifts during hover
- This is typically a flight controller tuning issue (INAV PIDs)
- Check GPS satellite count
- Verify compass calibration
- See [INAV_GUIDE.md](INAV_GUIDE.md) for FC-level tuning

#### Sluggish response to AI commands
- Widen RC range (`rc_min_value`/`rc_max_value`) for more roll/pitch authority
- Check `prediction_rate` is adequate (10+ Hz)

## Troubleshooting

For comprehensive troubleshooting information, see the [Troubleshooting Guide](TROUBLESHOOTING_GUIDE.md).

**Parameter-specific issues:**
- **Invalid YAML syntax** → Validate with: `python3 -c "import yaml; yaml.safe_load(open('swarm_params.yaml'))"`
- **Parameters not applied** → Check: `ros2 param list /node_name`
- **Performance issues** → Reduce control rates, telemetry rates

See [Parameter & Configuration Issues](TROUBLESHOOTING_GUIDE.md#parameter--configuration-issues) and [Performance Issues](TROUBLESHOOTING_GUIDE.md#performance-issues) in the Troubleshooting Guide.

## Best Practices

### 1. Version Control
- Commit `swarm_params.yaml` to git
- Create separate configs for different scenarios
- Document changes in commit messages

### 2. Backup Before Changes
```bash
cp swarm_params.yaml swarm_params.yaml.backup
```

### 3. Test in Simulation First
- Test parameter changes in safe environment
- Verify behavior before real hardware

### 4. Document Custom Configurations
- Add comments to explain why values were changed
- Note hardware-specific requirements

### 5. Start Conservative
- Low velocities, low altitude, close to home
- Increase limits gradually as confidence builds

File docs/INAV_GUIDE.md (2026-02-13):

# INAV Configuration Guide

Complete guide for configuring INAV flight controller parameters for autonomous drone operations.

> 📖 **Deep Dive:** For additional configuration tips and advanced tuning, see [Chapter 3.5: Additional Configurations](https://substack.com/home/post/p-180586067) on our Substack.

---

## Table of Contents

1. [Introduction](#introduction)
2. [Navigation Parameters](#navigation-parameters)
   - [Bank Angle Limits](#bank-angle-limits)
   - [Angle Mode Inclination](#angle-mode-inclination)
3. [Climb Rate Configuration](#climb-rate-configuration)
   - [Automatic Climb Rate](#automatic-climb-rate)
   - [Manual Climb Rate](#manual-climb-rate)
4. [GPS Position Control (XY Velocity PID)](#gps-position-control-xy-velocity-pid)
   - [Proportional (P) Term](#proportional-p-term)
   - [Integral (I) Term](#integral-i-term)
   - [Derivative (D) Term](#derivative-d-term)
   - [Feedforward (FF) Term](#feedforward-ff-term)
5. [Attitude Control (Level PIDs)](#attitude-control-level-pids)
   - [Level P Term](#level-p-term)
   - [Level D Term](#level-d-term)
6. [MSP Configuration](#msp-configuration)
   - [RC Override Channels](#rc-override-channels)
   - [Hover Throttle](#hover-throttle)
   - [Altitude Hold Throttle Mode](#altitude-hold-throttle-mode)
   - [Deadband Settings](#deadband-settings)
   - [I-Term Relax](#i-term-relax)
7. [GPS Settings](#gps-settings)
8. [Quick Reference](#quick-reference)
9. [Tuning Tips](#tuning-tips)
10. [Applying Configuration](#applying-configuration)

## Introduction

This guide provides detailed explanations of critical INAV parameters for multicopter autonomous flight. These settings control navigation behavior, position hold accuracy, and overall flight characteristics.

**Recommended Use Cases:**

- Autonomous GPS navigation
- Position hold (PosHold) mode
- Altitude hold (AltHold) mode
- Return to Home (RTH)
- Waypoint navigation
- MSP RC override for external control

## Navigation Parameters

### Bank Angle Limits

#### `nav_mc_bank_angle`

```
set nav_mc_bank_angle = 35
```

**Description:**
Maximum tilt angle (in degrees) used by autonomous navigation modes including PosHold, AltHold, and Waypoint navigation.

**Purpose:**

- Limits how aggressively the drone can tilt during GPS navigation
- Prevents excessive tilting that could lead to loss of control
- Ensures smooth, predictable flight paths

**Configuration:**

- **Value:** `35` degrees
- **Range:** Typically 5-45 degrees
- **Recommendation:**
  - Start conservative (15-20°) for testing
  - Increase for faster navigation if needed
  - Lower values = smoother, slower movements
  - Higher values = faster, more aggressive navigation

### Angle Mode Inclination

#### `max_angle_inclination_rll` and `max_angle_inclination_pit`

```
set max_angle_inclination_rll = 200
set max_angle_inclination_pit = 200
```

**Description:**
Maximum allowed tilt angle for ACRO/ANGLE mode manual flight.

**Units:** 0.1 degrees (150 = 15.0°)

**Purpose:**

- Limits manual stick input tilt angles
- Independent from autonomous navigation limits
- Safety limit for manual control

**Configuration:**

- **Value:** `200` (20°)
- **Recommendation:**
  - Conservative setting for smooth manual flight
  - Prevents novice pilots from over-tilting
  - Can be increased for sport/acrobatic flight (up to 500 = 50°)

## Climb Rate Configuration

### Automatic Climb Rate

#### `nav_mc_auto_climb_rate`

```
set nav_mc_auto_climb_rate = 300
```

**Description:**
Vertical speed used automatically by INAV during autonomous operations.

**Units:** cm/s (100 = 1.0 m/s)

**Used For:**

- Taking off in autonomous modes
- Landing sequences
- RTH altitude adjustments
- Waypoint altitude changes

**Configuration:**

- **Value:** `500` cm/s (5.0 m/s)
- **Recommendation:**
  - Conservative for safe takeoffs/landings
  - Increase to 100-150 cm/s (1-1.5 m/s) for faster altitude changes
  - Lower values provide smoother, safer operations

### Manual Climb Rate

#### `nav_mc_manual_climb_rate`

```
set nav_mc_manual_climb_rate = 300
```

**Description:**
Controls how throttle stick adjusts altitude while in AltHold or PosHold modes.

**Units:** cm/s (100 = 1.0 m/s)

**Behavior:**

- **Throttle above mid:** Climb at configured rate
- **Throttle below mid:** Descend at configured rate
- **Throttle at mid:** Hold current altitude

**Configuration:**

- **Value:** `200` cm/s (2.0 m/s)
- **Recommendation:**
  - 50-100 cm/s for precise control
  - Higher values = faster altitude changes with stick input
  - Match to `nav_mc_auto_climb_rate` for consistent behavior

## GPS Position Control (XY Velocity PID)

The XY velocity PID loop controls horizontal position accuracy during GPS navigation. These parameters directly affect how tightly the drone holds position.

### Proportional (P) Term

#### `nav_mc_vel_xy_p`

```
set nav_mc_vel_xy_p = 35
```

**Function:**
Proportional response to horizontal velocity error.

**Behavior:**

- **Higher P** → Stronger, more aggressive corrections
- **Lower P** → Softer, floatier feel
- **Too high** → Oscillations and overshooting
- **Too low** → Slow corrections, poor position hold

**Configuration:**

- **Value:** `35`
- **Tuning:**
  - Start at 25, increase gradually if position hold is loose
  - If drone oscillates in position hold, reduce P
  - Typical range: 10-40

### Integral (I) Term

#### `nav_mc_vel_xy_i`

```
set nav_mc_vel_xy_i = 18
```

**Function:**
Corrects accumulated position error over time.

**Behavior:**

- Handles long-term drift
- Compensates for wind and bias
- **Too high** → Oscillations, "toilet bowling" effect
- **Too low** → Position drift over time, especially in wind

**Configuration:**

- **Value:** `18`
- **Tuning:**
  - If drone drifts slowly over time, increase I
  - If drone circles or oscillates slowly, reduce I
  - Typical range: 5-20

**Warning:** The I term is powerful but can cause instability if too high. Tune conservatively.

### Derivative (D) Term

#### `nav_mc_vel_xy_d`

```
set nav_mc_vel_xy_d = 105
```

**Function:**
Damping term that smooths velocity corrections.

**Behavior:**

- Reduces oscillations
- **Higher D** → Snappier, tighter position lock
- **Too high** → Twitchy, jittery movements
- **Too low** → Bouncy, oscillatory corrections

**Configuration:**

- **Value:** `105` (high for tight hold)
- **Tuning:**
  - If drone bounces around target position, increase D
  - If drone feels twitchy or nervous, reduce D
  - Typical range: 30-120

### Feedforward (FF) Term

#### `nav_mc_vel_xy_ff`

```
set nav_mc_vel_xy_ff = 40
```

**Function:**
Reduces delay between stick input and movement in GPS modes.

**Behavior:**

- Improves responsiveness
- **Higher FF** → More direct feel, less lag
- **Too high** → Aggressive, overshooting
- **Too low** → Sluggish response

**Configuration:**

- **Value:** `40`
- **Tuning:**
  - If drone feels sluggish in GPS modes, increase FF
  - If drone overshoots targets, reduce FF
  - Typical range: 10-50

### XY Velocity PID Summary

```
set nav_mc_vel_xy_p = 35
set nav_mc_vel_xy_i = 18
set nav_mc_vel_xy_d = 105
set nav_mc_vel_xy_ff = 40
```

**Quick Tuning Guide:**

| Issue | Solution |
| --- | --- |
| Drone drifts from position | Increase P or I |
| Drone oscillates/bounces | Decrease P or increase D |
| Slow circles ("toilet bowling") | Decrease I |
| Overshooting target positions | Decrease P. |
| Twitchy, nervous movements | Decrease D |

## Attitude Control (Level PIDs)

Level PIDs control attitude stabilization in ANGLE/HORIZON modes and during GPS navigation. These are **NOT** GPS-related but affect how the drone levels itself.

### Level P Term

#### `mc_p_level`

```
set mc_p_level = 20
```

**Function:**
Controls how strongly the drone returns to level attitude.

**Behavior:**

- **Higher P** → More rigid, responsive leveling
- **Lower P** → Softer, less aggressive leveling
- **Too high** → Oscillations, overshooting level
- **Too low** → Slow to level, floaty feel

**Configuration:**

- **Value:** `20` (good for larger drones)
- **Tuning:**
  - Larger/heavier drones: 20-30
  - Smaller/lighter drones: 40-60
  - If drone wobbles when leveling, reduce P

### Level D Term

#### `mc_d_level`

```
set mc_d_level = 75
```

**Function:**
Damping for leveling response, reduces overshoot.

**Behavior:**

- Smooths stabilization
- Reduces bounce/oscillation when leveling
- **Too high** → Sluggish, soft feel
- **Too low** → Bouncy, oscillatory leveling

**Configuration:**

- **Value:** `75`
- **Tuning:**
  - If drone bounces when returning to level, increase D
  - If drone feels mushy or slow, reduce D
  - Typical range: 30-100

### Level PID Summary

```
set mc_p_level = 20
set mc_d_level = 75
```

These values provide smooth, predictable leveling for most medium-sized multirotors.

## MSP Configuration

### RC Override Channels

#### `msp_override_channels`

```
set msp_override_channels = 127
```

**Description:**
Bitmask defining which RC channels can be overridden via MSP (Multiwii Serial Protocol).

**Binary Explanation:**

- `127` in decimal = `01111111` in binary
- Each bit represents a channel (right to left: CH1, CH2, CH3, CH4, CH5, CH6, CH7, CH8)
- `1` = Channel can be overridden by MSP
- `0` = Channel cannot be overridden by MSP

**Configuration:**

- **Value:** `127` → MSP can override CH1-CH7
- **Alternative:** `255` → MSP can override CH1-CH8

**Use Case:**

- External flight computers (like this ROS2 system) can send RC commands via MSP
- Critical for autonomous flight using companion computers
- Allows programmatic control of roll, pitch, throttle, yaw, and aux channels

**Channel Mapping:**

- CH1: Roll
- CH2: Pitch
- CH3: Throttle
- CH4: Yaw
- CH5: ARM (AUX1)
- CH6: ANGLE mode (AUX2)
- CH7: ALT HOLD (AUX3)
- CH8: MSP RC Override Enable (AUX4)

### Hover Throttle

#### `nav_mc_hover_thr`

```
set nav_mc_hover_thr = 1500
```

**Description:**
RC value for throttle that achieves hover in altitude hold mode.

**Units:** RC PWM value (1000-2000)

**Purpose:**

- Baseline throttle for altitude hold calculations
- INAV uses this as reference point for climb/descent commands
- Affects how altitude hold interprets throttle deviations

**Configuration:**

- **Value:** `1500` (mid-stick)
- **Tuning:**
  - If drone climbs in AltHold with mid-throttle → Decrease value
  - If drone descends in AltHold with mid-throttle → Increase value
  - Typical range: 1400-1600
  - Must match actual hover throttle of your drone

**Important:** This should be calibrated to your specific drone's actual hover throttle point. This setting is per battery profile, so set it for all battery profiles you use.

### Altitude Hold Throttle Mode

#### `nav_mc_althold_throttle`

```
set nav_mc_althold_throttle = HOVER
```

**Description:**
Defines how throttle input is interpreted during altitude hold modes.

**Options:**

- `STICK` - Throttle stick directly controls climb/descent rate
- `MID_STICK` - Mid-stick position holds altitude, deviation controls climb/descent
- `HOVER` - Throttle at hover point holds altitude, more intuitive for most pilots

**Configuration:**

- **Value:** `HOVER`
- **Recommendation:**
  - `HOVER` is recommended for most use cases
  - Provides intuitive throttle behavior where hover throttle = hold altitude
  - Works well with `nav_mc_hover_thr` setting

---

### Deadband Settings

#### `pos_hold_deadband`

```
set pos_hold_deadband = 50
```

**Description:**
Stick deadband for position hold mode. Within this range, the drone holds position; outside, it moves.

**Units:** RC units (centered at 1500)

**Purpose:**

- Prevents unintended position changes from small stick movements
- Creates a "hold zone" around stick center
- Allows precise position holding without fighting stick noise

**Configuration:**

- **Value:** `50`
- **Recommendation:**
  - Higher values = larger deadband, easier to hold position
  - Lower values = more responsive to small inputs
  - Typical range: 20-100

#### `alt_hold_deadband`

```
set alt_hold_deadband = 50
```

**Description:**
Throttle stick deadband for altitude hold mode. Within this range, altitude is maintained.

**Units:** RC units (centered at 1500)

**Purpose:**

- Prevents unintended altitude changes from small throttle movements
- Creates a "hold zone" around throttle center/hover point
- Allows precise altitude holding

**Configuration:**

- **Value:** `50`
- **Recommendation:**
  - Higher values = larger deadband, easier to hold altitude
  - Lower values = more responsive to throttle inputs
  - Typical range: 20-100

### I-Term Relax

#### `mc_iterm_relax_cutoff`

```
set mc_iterm_relax_cutoff = 8
```

**Description:**
Cutoff frequency for I-term relax feature. Controls how quickly the I-term is suppressed during rapid stick movements.

**Units:** Hz

**Purpose:**

- Prevents I-term windup during aggressive maneuvers
- Reduces bounce-back after quick stick movements
- Improves overall flight feel and responsiveness

**Configuration:**

- **Value:** `8` Hz
- **Recommendation:**
  - Lower values = more aggressive I-term suppression
  - Higher values = less suppression, more traditional behavior
  - Typical range: 5-15 Hz
  - Lower values help with quick stops in position hold

## GPS Settings

### Minimum Satellites

#### `gps_min_sats`

```
set gps_min_sats = 6
```

**Description:**
Minimum number of GPS satellites required before GPS modes are enabled.

**Purpose:**

- Ensures sufficient GPS accuracy before allowing GPS navigation
- Prevents GPS modes from engaging with poor satellite coverage
- Safety feature to avoid unreliable position data

**Configuration:**

- **Value:** `6` satellites
- **Recommendation:**
  - Minimum safe value: 5
  - Better accuracy: 6-8
  - More satellites = better accuracy and reliability
  - Urban/obstructed areas may need lower threshold (5)
  - Open sky operations: can use 6-8 for better accuracy

**GPS Fix Quality:**

- 3-4 sats: Poor (not recommended)
- 5-6 sats: Adequate (minimum for navigation)
- 7-10 sats: Good (recommended)
- 10+ sats: Excellent

## Quick Reference

### Complete Configuration Script (INAV CLI commands)

Copy and paste this into INAV CLI to apply all settings:

```bash
# Navigation Angles
set nav_mc_bank_angle = 35
set max_angle_inclination_rll = 200
set max_angle_inclination_pit = 200

# Climb Rates
set nav_mc_auto_climb_rate = 300
set nav_mc_manual_climb_rate = 300

# XY Velocity PID (GPS Position Control)
set nav_mc_vel_xy_p = 35
set nav_mc_vel_xy_i = 18
set nav_mc_vel_xy_d = 105
set nav_mc_vel_xy_ff = 40

# Level PIDs (Attitude Control)
set mc_p_level = 20
set mc_d_level = 75

# Altitude Hold Settings
set nav_mc_althold_throttle = HOVER
set alt_hold_deadband = 50
set pos_hold_deadband = 50

# I-Term Relax
set mc_iterm_relax_cutoff = 8

# MSP Configuration
set msp_override_channels = 127

# GPS Settings
set gps_min_sats = 6

# Battery Profile Settings (apply to all battery profiles)
battery_profile 1
set nav_mc_hover_thr = 1500

# Save configuration
save
```

## Tuning Tips

### General Tuning Workflow

1. **Start Conservative:** Use default values from this guide
2. **Test Basic Flight:** Verify stable hover and basic navigation
3. **Tune One Parameter at a Time:** Change only one value per test flight
4. **Make Small Changes:** Adjust by 10-20% increments
5. **Document Changes:** Keep notes of what works and what doesn't

### Safety Checklist

Before autonomous flight:

- [ ] GPS has minimum satellite lock (5+)
- [ ] Position hold tested manually in open area
- [ ] Altitude hold stable at mid-throttle
- [ ] Return to home tested from short distance
- [ ] Failsafe configured and tested
- [ ] MSP override channels verified
- [ ] Manual mode available as backup

### INAV Tuning Quick Reference

These are common flight behavior issues specific to INAV parameter tuning. For comprehensive troubleshooting (hardware, software, system issues), see [TROUBLESHOOTING_GUIDE.md](TROUBLESHOOTING_GUIDE.md).

| Flight Behavior | Primary Adjustment | Secondary Adjustments |
| --- | --- | --- |
| **Position drift** | Increase `nav_mc_vel_xy_i` (10-12)  | Check GPS, calibrate compass |
| **Oscillations/bouncing**  | Decrease `nav_mc_vel_xy_p` (15-18)  | Increase `nav_mc_vel_xy_d` (60-70) |
| **Toilet bowling** | Decrease `nav_mc_vel_xy_i` (5-6) | Calibrate compass, check interference |
| **Sluggish response** | Increase `nav_mc_vel_xy_ff` (30-40) | Increase `nav_mc_vel_xy_p` (25-30) |
| **Altitude drift up/down** | Adjust `nav_mc_hover_thr` (±50) | Calibrate barometer, check for leaks  |

For detailed troubleshooting of these and other issues, see:

- [Flight Control Issues](TROUBLESHOOTING_GUIDE.md#flight-control-issues) - Detailed solutions with diagnostics
- [Hardware Issues](TROUBLESHOOTING_GUIDE.md#hardware-issues) - GPS, compass, sensor problems

## Applying Configuration

### Using INAV Configurator

1. Connect flight controller via USB
2. Open INAV Configurator
3. Go to **CLI** tab
4. Paste configuration commands
5. Type `save` and press Enter
6. Wait for FC to reboot

### Using MSP Commands

Configuration can also be applied programmatically via MSP serial protocol from companion computer.

### Verification

After applying configuration:

1. **Check in CLI:**

   ```bash
   get nav_mc_vel_xy_p
   get nav_mc_vel_xy_i
   # etc...
   ```

2. **Test Flight:**

   - Manual mode first
   - Then angle mode
   - Then altitude hold
   - Finally position hold
   - Test RTH last

3. **Monitor Behavior:**
   - Use blackbox logging
   - Review flight logs
   - Adjust as needed

## Additional Resources

**INAV Official Documentation:**

- [INAV Official Wiki](https://github.com/iNavFlight/inav/wiki)
- [INAV PID Tuning Guide](https://github.com/iNavFlight/inav/wiki/PID-tuning)
- [INAV GPS Configuration](https://github.com/iNavFlight/inav/wiki/GPS-and-Compass-setup)

## Notes

- These parameters are optimized for medium-sized multicopters (250-450mm)
- Smaller or larger drones may need different values
- Always test in safe, open areas with good GPS coverage
- Keep manual mode as backup on a switch
- Monitor battery voltage - low voltage affects position hold performance

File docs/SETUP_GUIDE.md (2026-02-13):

# Swarm ROS2 Environment Setup Guide

This guide provides step-by-step instructions for setting up the complete Swarm AI Integration drone control system on Ubuntu 22.04 and 24.04.

> 📖 **Deep Dive:** For a comprehensive understanding of the software architecture and how data flows through the system, see [Chapter 3: From Data to Motion](https://substack.com/home/post/p-177453660) on our Substack.

## Table of Contents

- [Nodes structure](#Nodes-structure)
- [Prerequisites](#prerequisites)
- [Quick Setup](#quick-setup)
- [Manual Setup](#manual-setup)
- [Hardware Configuration](#hardware-configuration)
- [Verification](#verification)
- [Troubleshooting](#troubleshooting)

## Nodes structure

```
                        ┌────────────────────┐
                        │  Lidar Reader Node │
                        │                    │
                        └────────────────────┘
                                  |
                                  │ /lidar_distance
     /fc/attitude_degrees         ↓
┌─────────────────┐      ┌──────────────────┐
│ Safety Monitor  │ <─── │  AI Adapter Node │ <──────────────┐
│      Node       │      │   (131-D Obs)    │                |
└─────────────────┘      └──────────────────┘                |
   │           ↑                  |                          |
   |           │                  │  /ai/observation         │ Read IMU and GPS from FC
   |           │                  │                          │ /fc/* topics
   |  /ai/observation             ↓                          |
   |           |        ┌────────────────────┐               |
   |           └────────│  AI Flight Node    │               |
   |                    │   (VEL vector)     │               |
   |                    └────────────────────┘               |
   |                              |                          |
   | /safety/override             | /ai/action               |
   | /safety/emergency_land       ↓                          |
   | /safety/status     ┌────────────────────┐               |
   └──────────────────> │  FC Adapter Node   │               |
                        │   (VEL to MSP)     │               |
                        └────────────────────┘               |
                                  |                          |
                                  | /fc/rc_override          |
                                  ↓                          |
                        ┌────────────────────┐               |
                        │  FC Comms Node     │ ──────────────┘
                        │  (MSP Protocol)    │
                        └────────────────────┘
                                  │ Full duplex real time communication
                                  │ MSP_SET_RAW_RC (Direct Serial)
                                  ↓
                        ┌──────────────────┐
                        │  INAV 8 FC       │
                        │  (Hardware)      │
                        └──────────────────┘
```

### Topic flow

| Node | Subscribes | Publishes |
|---|---|---|
| **Lidar Reader** | — | `/lidar_distance`, `/lidar_raw`, `/lidar_status` |
| **AI Adapter** | `/lidar_distance`, `/fc/gps_fix`, `/fc/attitude_euler`, `/fc/imu_raw`, `/ai/action` | `/ai/observation` |
| **Safety Monitor** | `/ai/observation`, `/fc/attitude_degrees` | `/safety/override`, `/safety/emergency_land`, `/safety/status` |
| **AI Flight** | `/ai/observation` | `/ai/action` |
| **FC Adapter** | `/ai/action`, `/safety/override`, `/fc/attitude_degrees` | `/fc/rc_override` |
| **FC Comms** | `/fc/rc_override` | All `/fc/*` topics |

### 131-D Observation Array

The `/ai/observation` topic published by the AI Adapter contains a 131-dimensional array:

| Index | Size | Component | Description |
|---|---|---|---|
| 0-2 | 3 | Position ENU | Relative position [E, N, U] in meters |
| 3-5 | 3 | Orientation | Euler angles [roll, pitch, yaw] in radians |
| 6-8 | 3 | Velocity | Linear velocity [vE, vN, vU] in m/s |
| 9-11 | 3 | Angular Velocity | Rotational velocity [wx, wy, wz] in rad/s |
| 12-111 | 100 | Action Buffer | History of 25 past actions (25 × 4) |
| 112-127 | 16 | LiDAR Distances | Normalized ray distances [0-1] |
| 128-130 | 3 | Goal Vector | Direction to goal, normalized |

> For detailed parameter descriptions, see [CONFIG_PARAMS_GUIDE.md](CONFIG_PARAMS_GUIDE.md#131-d-observation-array-structure).

## Prerequisites

### Hardware Requirements
- **Flight Controller**: INAV 8 compatible (connected via UART/Serial)
- **LiDAR Sensor**: I2C-based distance sensor (e.g., dTOF SEN0684  on address 0x08).
- **Onboard Computer**: Raspberry Pi 5 or Ubuntu 24.04 server (Also tested on Raspberry Pi 3b+ with Ubuntu 22.04 server).
- **GPS Module**: Connected to flight controller with UART.
- **IMU**: Integrated in flight controller.

### Software Requirements
- **OS**: Ubuntu 24.04 LTS
- **Internet Connection**: For downloading packages
- **Sudo Access**: Root privileges required for installation

### Hardware Connections
| Component | Interface | Device Path | Notes |
|---|---|---|---|
| Flight Controller | UART/Serial | `/dev/ttyAMA0` | 115200 baud |
| LiDAR (Down) | I2C Bus 1 | Address `0x08` | 100Hz polling |
| GPS | via FC | - | MSP protocol |
| IMU | via FC | - | MSP protocol |

---

## Quick Setup
> **Note:** This section assumes a fully working Langostino (or your specific drone). Otherwise, you will be running flight code without a drone.
### 1. Clone the Repository

```bash
cd ~
git clone <your-repo-url> swarm-ros
cd swarm-ros
```

### 2. Run Setup Script

```bash
sudo ./setup.sh
```

**What it does:**
- Installs ROS2 Jazzy (if needed)
- Installs all dependencies (Python, I2C, UART)
- Creates Python virtual environment for AI packages
- Configures hardware permissions (I2C, UART)
- Configures network (WiFi AP + Ethernet static IP)
- Fixes workspace ownership (prevents permission errors)
- Builds ROS2 workspace
- Installs PM2 process manager (auto-start on boot)

**Available Options:**
- `--skip-ros`: Skip ROS2 installation (if already installed)
- `--skip-hardware-check`: Skip hardware connectivity checks
- `--skip-pm2`: Skip PM2 installation (installed by default)

**Example with options:**
```bash
# Skip PM2 if you don't want process management
sudo ./setup.sh --skip-pm2

# Skip ROS2 install if already present
sudo ./setup.sh --skip-ros
```

> **Note**: The script automatically fixes workspace permissions and cleans old build artifacts, preventing common `colcon build` permission errors.

### 3. Log Out and Back In

**Important**: You must log out and log back in for group changes to take effect!

```bash
logout
# Or reboot
sudo reboot
```

### 4. Verify Installation

```bash
cd ~/swarm-ros
./verify_setup.sh
```

### 5. Launch the System

**Option A: Using PM2 (Recommended - Auto-installed)**

```bash
# Launch with PM2 process manager
./launch.sh

# View status
pm2 list

# View logs in real-time
pm2 logs

# Stop the system
pm2 stop swarm-ros-launched
```

**Option B: Direct ROS2 Launch**

```bash
# Source the environment (if not in .bashrc)
source /opt/ros/humble/setup.bash
source ~/swarm-ros/install/setup.bash

# Launch directly (runs in foreground)
ros2 launch swarm_ai_integration swarm_ai_launch.py
```

You can launch each node separately from the same terminal using PM2. See the [commands guide](COMMANDS_GUIDE.md).

> **PM2 Benefits**: Auto-restart on crash, survives reboots, centralized logging, resource monitoring

---

## Manual Setup

If you prefer to set up components individually:

### Step 1: Install ROS2 Jazzy

```bash
# Set up locale
sudo apt update && sudo apt install -y locales
sudo locale-gen en_US en_US.UTF-8
sudo update-locale LC_ALL=en_US.UTF-8 LANG=en_US.UTF-8

# Add ROS2 apt repository
sudo apt install -y software-properties-common
sudo add-apt-repository universe
sudo apt update && sudo apt install -y curl gnupg lsb-release

curl -sSL https://raw.githubusercontent.com/ros/rosdistro/master/ros.key \
  -o /usr/share/keyrings/ros-archive-keyring.gpg

echo "deb [arch=$(dpkg --print-architecture) signed-by=/usr/share/keyrings/ros-archive-keyring.gpg] \
  http://packages.ros.org/ros2/ubuntu $(source /etc/os-release && echo $UBUNTU_CODENAME) main" \
  | sudo tee /etc/apt/sources.list.d/ros2.list > /dev/null

# Install ROS2
sudo apt update
sudo apt install -y ros-jazzy-ros-base
sudo apt install -y ros-dev-tools python3-colcon-common-extensions

# Initialize rosdep
sudo rosdep init
rosdep update
```

### Step 2: Install System Dependencies

```bash
sudo apt install -y \
    build-essential \
    cmake \
    git \
    python3-pip \
    python3-dev \
    python3-venv \
    libi2c-dev \
    i2c-tools \
    python3-smbus \
    python3-serial \
    python3-numpy \
    python3-scipy
```

### Step 3: Install Python Dependencies

**System packages (for ROS nodes):**
```bash
pip3 install --upgrade pip
pip3 install numpy scipy pyserial smbus2
```

**Virtual environment for AI Flight Node:**
```bash
# Create virtual environment
python3 -m venv ~/ai_flight_node_env

# Activate virtual environment
source ~/ai_flight_node_env/bin/activate

# Install AI packages from requirements file
cd ~/swarm-ros
pip install --upgrade pip
pip install -r requirements.txt

# Deactivate (optional)
deactivate
```

The `requirements.txt` file contains:
- numpy>=1.24,<2.0
- typing-extensions
- gymnasium
- stable-baselines3
- torch

### Step 4: Configure I2C (for LiDAR)

```bash
# Enable I2C module
sudo modprobe i2c-dev
echo "i2c-dev" | sudo tee -a /etc/modules

# Add user to i2c group
sudo usermod -a -G i2c $USER

# Set I2C permissions
echo 'KERNEL=="i2c-[0-9]*", GROUP="i2c", MODE="0660"' \
  | sudo tee /etc/udev/rules.d/99-i2c.rules

sudo udevadm control --reload-rules
sudo udevadm trigger
```

### Step 5: Configure UART (for Flight Controller)

```bash
# Add user to dialout group
sudo usermod -a -G dialout $USER

# Set UART permissions
cat << EOF | sudo tee /etc/udev/rules.d/99-serial.rules
KERNEL=="ttyAMA[0-9]*", GROUP="dialout", MODE="0660"
KERNEL=="ttyUSB[0-9]*", GROUP="dialout", MODE="0660"
KERNEL=="ttyACM[0-9]*", GROUP="dialout", MODE="0660"
EOF

sudo udevadm control --reload-rules
sudo udevadm trigger
```

### Step 6: Configure Network (WiFi AP + Ethernet)

```bash
# Run the network setup script
cd ~/swarm-ros
chmod +x network_setup.sh
sudo ./network_setup.sh
```

**What it configures:**
- Static IP on `eth0`: `192.168.10.1/24`
- DHCP on `wlan0` for connecting to known WiFi networks
- Automatic WiFi Access Point fallback
- AP SSID: `Swarm_AP`
- AP Password: `swarmascend`
- DHCP server range: `192.168.10.10 - 192.168.10.50`
- Automatic network manager service

The system will automatically:
1. Try to connect to known WiFi networks on boot
2. If no known network is found, create an Access Point
3. Allow you to SSH into the drone at `192.168.10.1`

To add known WiFi networks, edit `/etc/wifi_networks.conf`:
```bash
sudo nano /etc/wifi_networks.conf
```

Add networks in the format:
```
SSID:password
MyHomeWiFi:mypassword123
WorkNetwork:workpassword
```

### Step 7: Build ROS2 Workspace

```bash
cd ~/swarm-ros
source /opt/ros/jazzy/setup.bash
rosdep install --from-paths src --ignore-src -r -y
colcon build --symlink-install
```

### Step 8: Configure Environment

Add to `~/.bashrc`:

```bash
# ROS2 Environment
source /opt/ros/jazzy/setup.bash
source ~/swarm-ros/install/setup.bash

# ROS2 Configuration
export ROS_DOMAIN_ID=0
export ROS_LOCALHOST_ONLY=0
```

Apply changes:
```bash
source ~/.bashrc
```

---

## Hardware Configuration

### I2C LiDAR Setup

#### Enable I2C on Raspberry Pi

Edit `/boot/firmware/config.txt`:
```bash
sudo nano /boot/firmware/config.txt
```

Add or uncomment:
```
dtparam=i2c_arm=on
```

Reboot:
```bash
sudo reboot
```

#### Verify I2C Connection

Check if I2C device is detected:
```bash
i2cdetect -y 1
```

You should see `08` in the output grid (LiDAR address).

### UART Flight Controller Setup

#### Enable UART on Raspberry Pi

Edit `/boot/firmware/config.txt`:
```bash
sudo nano /boot/firmware/config.txt
```

Add:
```
enable_uart=1
```

#### Disable Serial Console (if needed)

Edit `/boot/firmware/cmdline.txt` and remove:
```
console=serial0,115200
```

#### Verify UART Connection

```bash
ls -l /dev/ttyAMA0
```

Should show device with `crw-rw----` permissions and group `dialout`.

### Network Setup

The Swarm system is configured with a dual-network setup for maximum flexibility:

#### Network Interfaces

| Interface | Mode | IP Address | Purpose |
|---|---|---|---|
| `eth0` | Static IP | `192.168.10.1/24` | Main communication interface |
| `wlan0` | DHCP/AP | Auto/`192.168.10.1` | WiFi client or Access Point |

#### WiFi Auto-Manager

The system includes an automatic WiFi manager that:
1. **Scans** for known WiFi networks on boot
2. **Connects** to the first available known network (client mode)
3. **Falls back** to Access Point mode if no known networks found

#### Access Point Details

When in AP mode:
- **SSID**: `Swarm_AP`
- **Password**: `swarmascend`
- **IP Address**: `192.168.10.1`
- **DHCP Range**: `192.168.10.10 - 192.168.10.50`

#### Connect to the Swarm

**Via Access Point:**
```bash
# Connect your laptop to Swarm_AP WiFi network
# Password: swarmascend

# SSH into the drone
ssh pi@192.168.10.1
```

**Via Ethernet:**
```bash
# Connect ethernet cable to your laptop
# Configure your laptop's ethernet to 192.168.10.x (x != 1)

# SSH into the drone
ssh pi@192.168.10.1
```

#### Add Known WiFi Networks

Edit the known networks file:
```bash
sudo nano /etc/wifi_networks.conf
```

Add networks (one per line):
```
SSID:password
MyHomeWiFi:mypassword123
WorkNetwork:workpassword
```

Restart the WiFi manager service:
```bash
sudo systemctl restart wifi-manager.service
```

#### Network Service Management

```bash
# Check WiFi manager status
sudo systemctl status wifi-manager.service

# View WiFi manager logs
sudo journalctl -u wifi-manager.service -f

# Manually start Access Point
sudo systemctl start hostapd
sudo systemctl start dnsmasq

# Manually stop Access Point
sudo systemctl stop hostapd
sudo systemctl stop dnsmasq

# Check current network status
ip addr show
iwconfig
```

---

## Verification

### Run Verification Script

```bash
cd ~/swarm-ros
./verify_setup.sh
```

The script checks:
- ✓ Ubuntu version
- ✓ ROS2 Jazzy installation
- ✓ Python dependencies
- ✓ I2C configuration and LiDAR detection
- ✓ UART configuration and FC connection
- ✓ Workspace build status
- ✓ Launch files and configuration

### Manual Hardware Tests

#### Test I2C Communication

```bash
# Scan I2C bus
i2cdetect -y 1

# Read from LiDAR (if using i2c-tools)
i2cget -y 1 0x08 0x24 w
```

#### Test UART Communication

```bash
# Check if device is accessible
ls -l /dev/ttyAMA0

# Monitor serial data (Ctrl+C to exit)
cat /dev/ttyAMA0
```

#### Test ROS2 Nodes

```bash
# Source environment
source /opt/ros/humble/setup.bash
source ~/swarm-ros/install/setup.bash

# List available nodes
ros2 pkg executables swarm_ai_integration

# Test individual node
ros2 run swarm_ai_integration lidar_reader_node
```

---

## Troubleshooting

For comprehensive troubleshooting, see [TROUBLESHOOTING_GUIDE.md](TROUBLESHOOTING_GUIDE.md).

**Setup-specific quick fixes:**

| Issue | Quick Solution |
|---|---|
| **ros2: command not found** | `source /opt/ros/jazzy/setup.bash` |
| **Permission denied (I2C/UART)** | `sudo usermod -a -G i2c,dialout $USER`, then logout |
| **Build permission errors** | `sudo chown -R $USER:$USER ~/swarm-ros && rm -rf build install log` |
| **Virtual env in /root** | `sudo rm -rf /root/ai_flight_node_env && python3 -m venv ~/ai_flight_node_env` |
| **Cannot connect to Swarm_AP** | `sudo systemctl restart wifi-manager.service` |
| **Package not found** | `rm -rf build install log && colcon build --symlink-install` |

See the following sections in the Troubleshooting Guide for detailed solutions:
- [Build & Installation Issues](TROUBLESHOOTING_GUIDE.md#build--installation-issues)
- [Hardware Issues](TROUBLESHOOTING_GUIDE.md#hardware-issues)
- [Network & Connectivity Issues](TROUBLESHOOTING_GUIDE.md#network--connectivity-issues)

## Configuration Files

### Main Configuration

**Location**: `src/swarm_ai_integration/config/swarm_params.yaml`

Key parameters to configure:
- Flight controller serial port
- LiDAR I2C address
- Safety limits (altitude, velocity, battery)
- AI model path

### Launch Configuration

**Location**: `src/swarm_ai_integration/launch/swarm_ai_launch.py`

Modify to enable/disable nodes as needed.

## Process Management with PM2

PM2 is **installed by default** by the setup script and provides powerful process management features.

### Quick Start

```bash
# Start the ROS system with PM2
./launch.sh

# Check status
pm2 list
```

### Common PM2 Commands

```bash
# View logs in real-time (all processes)
pm2 logs

# View logs for specific process
pm2 logs swarm-ros-launched

# Monitor resource usage (CPU, memory)
pm2 monit

# Stop the system
pm2 stop swarm-ros-launched

# Restart the system
pm2 restart swarm-ros-launched

# Stop all PM2 processes
pm2 stop all

# Restart all PM2 processes
pm2 restart all

# Delete process from PM2
pm2 delete swarm-ros-launched

# Show detailed process info
pm2 show swarm-ros-launched
```

### Auto-Start on Boot

PM2 is **automatically configured** to start on boot by the setup script:

```bash
# Verify startup configuration
pm2 startup

# Save current process list (auto-start this on boot)
pm2 save

# List saved processes
pm2 list
```

After running `pm2 save`, your ROS system will automatically start when the Raspberry Pi boots!

### Disable Auto-Start

If you don't want auto-start:

```bash
# Remove from startup
pm2 unstartup systemd

# Or delete specific process
pm2 delete swarm-ros-launched
pm2 save
```

### PM2 Log Files

PM2 stores logs in `~/.pm2/logs/`:

```bash
# View log file locations
ls -la ~/.pm2/logs/

# Tail error logs
tail -f ~/.pm2/logs/swarm-ros-launched-error.log

# Tail output logs
tail -f ~/.pm2/logs/swarm-ros-launched-out.log

# Clear all logs
pm2 flush
```

### Advanced PM2 Features

```bash
# Restart on file changes (development)
pm2 start launch.sh --watch

# Set environment variables
pm2 start launch.sh --name swarm-ai --env production

# Limit memory and restart on threshold
pm2 start launch.sh --max-memory-restart 1G

# Run multiple instances (if needed)
pm2 scale swarm-ros-launched 2
```

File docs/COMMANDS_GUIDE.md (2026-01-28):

# System Commands Guide

Quick reference for launching and managing the Swarm AI Integration system.

## Table of Contents

1. [Quick Start](#quick-start)
2. [Launch Methods](#launch-methods)
3. [Individual Node Commands](#individual-node-commands)
4. [PM2 Management](#pm2-management)
5. [ROS2 Direct Commands](#ros2-direct-commands)
6. [Troubleshooting](#troubleshooting)

## Quick Start

### Launch Entire System

**Recommended:** Use the launch script for easy startup

```bash
cd ~/swarm-ros
./launch.sh
```

Or manually with PM2:

```bash
pm2 start "ros2 launch swarm_ai_integration swarm_ai_launch.py" --name swarm_ai
```

Or directly with ROS2:

```bash
cd ~/swarm-ros
source install/setup.bash
ros2 launch swarm_ai_integration swarm_ai_launch.py
```

## Launch Methods

### Method 1: Launch Script (Recommended)

**Best for:** Production use, automatic startup, easy management

```bash
./launch.sh
```

**Features:**
- Starts all nodes automatically
- Uses PM2 for process management
- Auto-restart on failure
- Logs to files
- Background execution

---

### Method 2: ROS2 Launch File

**Best for:** Development, debugging, testing

```bash
ros2 launch swarm_ai_integration swarm_ai_launch.py
```

**Features:**
- All nodes in one terminal
- Direct log output to console
- Easy to stop (Ctrl+C)
- Good for testing configuration changes

---

### Method 3: Individual Nodes with PM2

**Best for:** Testing specific components, custom configurations

See [Individual Node Commands](#individual-node-commands) below.

## Individual Node Commands

Launch specific nodes independently using PM2. Useful for testing, debugging, or custom configurations.

### 1. LiDAR Reader Node

**Purpose:** Reads distance data from LiDAR sensor via I2C

```bash
pm2 start "ros2 run swarm_ai_integration lidar_reader_node.py" --name lidar_reader
```

**Publishes to:**
- `/lidar/distance` - Distance measurements in meters

**Requirements:**
- I2C enabled and configured
- LiDAR connected to I2C bus 1 at address 0x08
- User in `i2c` group

**Test connection:**
```bash
i2cdetect -y 1
# Should show device at address 0x08
```

---

### 2. Flight Controller Communication Node

**Purpose:** Communicates with INAV flight controller via MSP serial protocol

```bash
pm2 start "ros2 run swarm_ai_integration fc_comms_node.py" --name fc_comms
```

**Publishes:**
- `/fc/gps_position` - GPS coordinates
- `/fc/gps_speed_course` - Speed and heading
- `/fc/attitude_euler` - Roll, pitch, yaw
- `/fc/altitude` - Barometric altitude and climb rate
- `/fc/battery_status` - Voltage and current

**Subscribes:**
- `/fc/rc_override` - RC channel overrides

**Requirements:**
- Serial port `/dev/ttyAMA0` available
- User in `dialout` group
- FC configured for MSP at 115200 baud

**Test connection:**
```bash
ls -l /dev/ttyAMA0
# Should be readable/writable
```

---

### 3. AI Adapter Node

**Purpose:** Transforms sensor data into observations for the AI model

```bash
pm2 start "ros2 run swarm_ai_integration ai_adapter_node.py" --name ai_adapter
```

**Subscribes:**
- `/lidar/distance`
- `/fc/gps_position`
- `/fc/attitude_euler`
- `/fc/altitude`

**Publishes:**
- `/ai/observation` - Formatted observation vector for AI

**Note:** This node acts as the bridge between raw sensor data and the AI model.

---

### 4. AI Flight Node

**Purpose:** Runs the trained AI model and generates flight commands

```bash
pm2 start "ros2 run swarm_ai_integration ai_flight_node.py --ros-args -p model_path:=/home/pi/swarm-ros/model/UID_3.zip" --name ai_flight
```

**Subscribes:**
- `/ai/observation` - State observations from sensors

**Publishes:**
- `/ai/action` - Flight commands (vx, vy, vz, speed)

**Parameters:**
- `model_path` - Path to trained model file (.zip)

**Requirements:**
- Model file exists at specified path
- Virtual environment configured (see setup.sh)
- PyTorch and stable-baselines3 installed

**Common model paths:**
```bash
# Development model
-p model_path:=~/swarm-ros/model/UID_3.zip

# Production model
-p model_path:=/opt/swarm/model/production.zip
```

---

### 5. Flight Controller Adapter Node

**Purpose:** Converts AI velocity commands to RC values and sends to FC via MSP

```bash
pm2 start "ros2 run swarm_ai_integration fc_adapter_node.py" --name fc_adapter
```

**Subscribes:**
- `/ai/action` - Velocity commands from AI
- `/fc/gps_speed_course` - Current velocity
- `/fc/attitude_euler` - Current orientation
- `/fc/altitude` - Current altitude and climb rate
- `/safety/override` - Safety override signal

**Publishes:**
- `/fc_adapter/status` - Node status
- `/fc_adapter/velocity_error` - Control error metrics
- `/fc/rc_override` - RC channel values

**Features:**
- Closed-loop velocity control with PID
- Direct MSP communication
- Pre-arm sequence (30 seconds)
- Warmup phase (40 frames)
- Throttle safety (1000 during arming)
- Rate limiting on throttle changes

**Important:** This node handles arming and RC override. Ensure parameters are correct.

---

### 6. Black Box Recorder Node

**Purpose:** Records all flight data to CSV files for analysis

```bash
pm2 start "ros2 run swarm_ai_integration black_box_recorder_node.py --ros-args -p log_directory:=~/swarm-ros/flight-logs" --name black_box
```

**Subscribes:**
- `/ai/observation`
- `/ai/action`
- `/fc/gps_position`
- `/fc/attitude_euler`
- `/fc/battery_status`
- `/lidar/distance`

**Parameters:**
- `log_directory` - Directory for flight logs

**Output:**
- CSV files with timestamp: `flight_log_YYYYMMDD_HHMMSS.csv`

**Log directory:**
```bash
# Default
-p log_directory:=~/swarm-ros/flight-logs

# Custom
-p log_directory:=/mnt/usb/logs
```

**View logs:**
```bash
ls -lh ~/swarm-ros/flight-logs/
tail -f ~/swarm-ros/flight-logs/flight_log_*.csv
```

## PM2 Management

### View Running Processes

```bash
pm2 list
```

**Output shows:**
- Process name
- Status (online/stopped/errored)
- CPU and memory usage
- Uptime
- Restart count

---

### View Logs

**All logs:**
```bash
pm2 logs
```

**Specific node:**
```bash
pm2 logs swarm_ai
pm2 logs lidar_reader
pm2 logs fc_comms
pm2 logs ai_adapter
pm2 logs ai_flight
pm2 logs fc_adapter
pm2 logs black_box
```

**Filter last N lines:**
```bash
pm2 logs --lines 100
```

**Clear logs:**
```bash
pm2 flush
```

---

### Process Control

**Stop all:**
```bash
pm2 stop all
```

**Stop specific node:**
```bash
pm2 stop swarm_ai
pm2 stop fc_adapter
```

**Restart all:**
```bash
pm2 restart all
```

**Restart specific node:**
```bash
pm2 restart fc_comms
```

**Delete process (removes from PM2):**
```bash
pm2 delete swarm_ai
pm2 delete all
```

---

### Monitoring

**Real-time monitoring:**
```bash
pm2 monit
```

**Process information:**
```bash
pm2 show swarm_ai
```

**Save process list (for auto-start on boot):**
```bash
pm2 save
```

**Setup auto-start on boot:**
```bash
pm2 startup
# Follow the instructions shown
```

---

## ROS2 Direct Commands

### Run Individual Nodes (Without PM2)

Useful for debugging with direct console output.

**LiDAR Reader:**
```bash
ros2 run swarm_ai_integration lidar_reader_node.py
```

**FC Communications:**
```bash
ros2 run swarm_ai_integration fc_comms_node.py
```

**AI Adapter:**
```bash
ros2 run swarm_ai_integration ai_adapter_node.py
```

**AI Flight:**
```bash
ros2 run swarm_ai_integration ai_flight_node.py --ros-args -p model_path:=~/swarm-ros/model/UID_3.zip
```

**FC Adapter:**
```bash
ros2 run swarm_ai_integration fc_adapter_node.py
```

**Black Box Recorder:**
```bash
ros2 run swarm_ai_integration black_box_recorder_node.py --ros-args -p log_directory:=~/swarm-ros/flight-logs
```

---

### ROS2 Diagnostic Commands

**List active nodes:**
```bash
ros2 node list
```

**List all topics:**
```bash
ros2 topic list
```

**Monitor specific topic:**
```bash
ros2 topic echo /ai/action
ros2 topic echo /fc/gps_position
ros2 topic echo /lidar/distance
```

**Check topic frequency:**
```bash
ros2 topic hz /ai/action
ros2 topic hz /fc/gps_position
```

**Show topic info:**
```bash
ros2 topic info /ai/action
```

**Node information:**
```bash
ros2 node info /lidar_reader_node
ros2 node info /fc_comms_node
ros2 node info /fc_adapter_velocity_node
```

**Check parameters:**
```bash
ros2 param list /fc_adapter_velocity_node
ros2 param get /fc_adapter_velocity_node control_rate_hz
```

**Set parameters at runtime:**
```bash
ros2 param set /fc_adapter_velocity_node kp_xy 25.0
```

## Troubleshooting

For comprehensive troubleshooting information, see the [Troubleshooting Guide](TROUBLESHOOTING_GUIDE.md).

**Quick diagnostics:**
```bash
# Check system status
pm2 list
ros2 node list

# Check logs
pm2 logs

# Hardware checks
i2cdetect -y 1        # LiDAR
ls -l /dev/ttyAMA0    # FC serial
```

**Common issues:**
- **Node won't start** → Check PM2 logs: `pm2 logs <node_name>`
- **No data on topics** → Verify node is running: `ros2 node list`
- **Permission errors** → Add user to groups: `sudo usermod -a -G i2c,dialout $USER`
- **High CPU** → Reduce control rates in swarm_params.yaml

See [TROUBLESHOOTING_GUIDE.md](TROUBLESHOOTING_GUIDE.md) for detailed solutions.

## Quick Command Reference

| Task | Command |
|---|---|
| **Start system** | `./launch.sh` or `pm2 start ...` |
| **Stop all** | `pm2 stop all` |
| **Restart all** | `pm2 restart all` |
| **View logs** | `pm2 logs` |
| **List processes** | `pm2 list` |
| **Monitor** | `pm2 monit` |
| **ROS2 launch** | `ros2 launch swarm_ai_integration swarm_ai_launch.py` |
| **List nodes** | `ros2 node list` |
| **List topics** | `ros2 topic list` |
| **Echo topic** | `ros2 topic echo /topic/name` |
| **Node info** | `ros2 node info /node_name` |
| **Check I2C** | `i2cdetect -y 1` |
| **Check serial** | `ls -l /dev/ttyAMA0` |

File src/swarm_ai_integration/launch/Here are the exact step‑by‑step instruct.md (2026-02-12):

Here are the exact step‑by‑step instructions (1 by 1) to run Langostino autonomously, including the INAV waypoint and GPS check.

Previous:

0. TEST GPS
1. Test manual flight (modes)

0) INAV setup (via USB cable)

Connect the flight controller to your laptop with USB.
Open INAV Configurator.
Connect to the FC.
Go to Mission Control / Mission Planner.
Create at least 1 waypoint (the system reads WP #1).
Save/Upload the mission to the FC.
Disconnect USB.
1) Power and GPS

Power the drone (battery connected).
Wait for GPS lock.
On the Pi, check satellites:
ros2 topic echo /fc/gps_satellites
Make sure it shows 5 or more satellites (default requirement).
2) Start LiDAR

pm2 start "ros2 run swarm_ai_integration lidar_reader_node.py" --name lidar_reader
What it does: reads LiDAR over I2C (addr 0x08) and publishes /lidar_distance.

3) Start FC communications (MSP)

pm2 start "ros2 run swarm_ai_integration fc_comms_node.py" --name fc_comms
What it does: connects to /dev/ttyAMA0, publishes FC telemetry, and sends RC overrides.

4) Start AI adapter

pm2 start "ros2 run swarm_ai_integration ai_adapter_node.py" --name ai_adapter
What it does: builds the 131‑D AI observation from telemetry + LiDAR.

5) Start AI flight model

pm2 start "ros2 run swarm_ai_integration ai_flight_node.py --ros-args -p model_path:=/home/pi/swarm-ros/model/UID_3.zip" --name ai_flight
What it does: runs inference at 10 Hz and publishes /ai/action.

6) Start FC adapter (AI → RC)

pm2 start "ros2 run swarm_ai_integration fc_adapter_node.py" --name fc_adapter
What it does: converts AI actions to RC overrides and arms/rises/yaw‑aligns.

7) Start black box recorder

pm2 start "ros2 run swarm_ai_integration black_box_recorder_node.py --ros-args -p log_directory:=~/flight-logs" --name black_box
What it does: logs all key topics to JSONL for analysis.

8) Start safety monitor

pm2 start "ros2 run swarm_ai_integration safety_monitor_node.py" --name safety_monitor
What it does: monitors attitude/altitude/geofence and can trigger /safety/override.

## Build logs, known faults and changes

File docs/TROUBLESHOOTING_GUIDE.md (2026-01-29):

# Troubleshooting Guide

Comprehensive troubleshooting reference for the Swarm AI Integration system.

---

## Table of Contents

1. [Quick Diagnostics](#quick-diagnostics)
2. [System & ROS2 Issues](#system--ros2-issues)
3. [Hardware Issues](#hardware-issues)
   - [Raspberry Pi Boot Configuration](#raspberry-pi-boot-configuration-bootfirmwareconfigtxt)
   - [I2C LiDAR Issues](#i2c-lidar-issues)
   - [Flight Controller UART Issues](#flight-controller-uart-issues)
   - [GPS Issues](#gps-issues)
4. [Build & Installation Issues](#build--installation-issues)
5. [Network & Connectivity Issues](#network--connectivity-issues)
6. [Runtime & Node Issues](#runtime--node-issues)
7. [Parameter & Configuration Issues](#parameter--configuration-issues)
8. [Performance Issues](#performance-issues)
9. [Safety & Emergency Procedures](#safety--emergency-procedures)

---

## Quick Diagnostics

### Run System Diagnostics

```bash
# Check system status
cd ~/swarm-ros
./verify_setup.sh

# Check running nodes
ros2 node list

# Check topics
ros2 topic list

# Check PM2 processes
pm2 list
```

### Check Logs

```bash
# PM2 logs (all nodes)
pm2 logs

# Specific node logs
pm2 logs fc_adapter --lines 100

# ROS2 console output
ros2 topic echo /rosout
```

### Quick Hardware Checks

```bash
# I2C LiDAR
i2cdetect -y 1

# Serial FC
ls -l /dev/ttyAMA0
sudo lsof /dev/ttyAMA0

# GPS status
ros2 topic echo /fc/gps_position

# Groups
groups  # Should include i2c, dialout
```

---

## System & ROS2 Issues

### System Won't Start

#### `ros2: command not found`

**Cause:** ROS2 environment not sourced.

**Solution:**
```bash
# Source environment
source /opt/ros/humble/setup.bash
source ~/swarm-ros/install/setup.bash

# Make permanent
echo "source /opt/ros/humble/setup.bash" >> ~/.bashrc
echo "source ~/swarm-ros/install/setup.bash" >> ~/.bashrc
source ~/.bashrc
```

---

#### Workspace Not Built

**Symptoms:**
- Package not found errors
- Missing install directory

**Solution:**
```bash
cd ~/swarm-ros
ls -l install/  # Should contain setup.bash and package folders

# If missing, rebuild
colcon build --symlink-install
source install/setup.bash
```

---

#### Wrong ROS_DISTRO

**Check:**
```bash
echo $ROS_DISTRO
# Should show: humble (for 22.04) or jazzy (for 24.04)
```

**Solution:**
```bash
source /opt/ros/humble/setup.bash
```

---

### Package Not Found After Building

**Solution:**
```bash
cd ~/swarm-ros

# Clean old artifacts
rm -rf build install log

# Rebuild
colcon build --symlink-install
source install/setup.bash
```

---

## Hardware Issues

### Raspberry Pi Boot Configuration (`/boot/firmware/config.txt`)

The Raspberry Pi uses `/boot/firmware/config.txt` to configure hardware interfaces at boot time. Incorrect configuration here is a common cause of I2C and UART communication failures with the flight controller and sensors.

#### Verifying Current Configuration

```bash
# View current config.txt
cat /boot/firmware/config.txt

# Check if I2C is enabled
grep -E "^dtparam=i2c" /boot/firmware/config.txt

# Check UART settings
grep -E "^enable_uart|^dtoverlay=disable-bt|^\[pi5\]|^dtoverlay=uart" /boot/firmware/config.txt
```

#### Required Settings for Swarm System

Your `/boot/firmware/config.txt` should contain these lines:

```ini
# I2C for LiDAR sensor
dtparam=i2c_arm=on

# UART for Flight Controller
enable_uart=1
dtoverlay=disable-bt

# Pi 5 ONLY - required for GPIO 14/15 UART
[pi5]
dtoverlay=uart0-pi5
```

#### Common Configuration Errors

| Error | Symptom | Solution |
|---|---|---|
| Missing `dtparam=i2c_arm=on` | `/dev/i2c-1` doesn't exist | Add the line and reboot |
| Missing `enable_uart=1` | `/dev/ttyAMA0` doesn't exist | Add the line and reboot |
| Missing `dtoverlay=disable-bt` | UART conflicts with Bluetooth | Add the line and reboot |
| Pi 5 missing `[pi5]` section | UART not mapped to GPIO 14/15 | Add `[pi5]` section with `dtoverlay=uart0-pi5` |
| Duplicate entries | Unpredictable behavior | Remove duplicates, keep one of each |
| Syntax errors (typos) | Setting not applied | Check spelling exactly |

#### Pi 3 vs Pi 5 UART Differences

**Raspberry Pi 3B / 3B+:**
- UART is on `/dev/ttyAMA0` by default after disabling Bluetooth
- Only needs `enable_uart=1` and `dtoverlay=disable-bt`
- Tested with: `setup_22_04.sh` on Raspberry Pi 3B and 3B+

**Raspberry Pi 5:**
- UART requires explicit overlay configuration
- Must add `[pi5]` section with `dtoverlay=uart0-pi5`
- Creates `/dev/ttyAMA0` mapped to GPIO 14 (TX) and GPIO 15 (RX)
- May also show `/dev/ttyAMA10` (different UART peripheral)
- Tested with: `setup_24_04.sh` on Raspberry Pi 5 (4GB and 8GB versions)

> **Note:** Raspberry Pi 4 has not been tested yet. It may work with either setup script, but UART configuration could differ. If you test on Pi 4, please report your results.

```bash
# Check Pi model
cat /proc/device-tree/model

# List available serial devices
ls -la /dev/ttyAMA*
```

#### Fixing Missing I2C Configuration

```bash
# Check if I2C is enabled
ls /dev/i2c*
# Should show /dev/i2c-1

# If missing, add to config.txt
sudo nano /boot/firmware/config.txt

# Add this line (if not present):
dtparam=i2c_arm=on

# Save and reboot
sudo reboot

# After reboot, verify
i2cdetect -y 1
```

#### Fixing Missing UART Configuration

```bash
# Check if UART device exists
ls -la /dev/ttyAMA0

# If missing on Pi 4:
sudo nano /boot/firmware/config.txt
# Add:
enable_uart=1
dtoverlay=disable-bt

# If missing on Pi 5, also add:
[pi5]
dtoverlay=uart0-pi5

# Disable Bluetooth services
sudo systemctl disable hciuart
sudo systemctl disable bluetooth

# Reboot
sudo reboot
```

#### cmdline.txt Serial Console Conflicts

The kernel command line (`/boot/firmware/cmdline.txt`) may have serial console enabled, which conflicts with flight controller communication.

**Check for conflicts:**
```bash
cat /boot/firmware/cmdline.txt
# Look for: console=serial0,115200 or console=ttyAMA0,115200
```

**Remove serial console (if present):**
```bash
# Backup first
sudo cp /boot/firmware/cmdline.txt /boot/firmware/cmdline.txt.backup

# Edit and remove console=serial0,115200 and console=ttyAMA0,115200
sudo nano /boot/firmware/cmdline.txt

# Reboot
sudo reboot
```

#### Serial Getty Service Conflicts

The `serial-getty` service can lock the UART port, preventing flight controller communication.

**Check if serial-getty is running:**
```bash
# Pi 4
sudo systemctl status serial-getty@ttyAMA0.service

# Pi 5 (check both)
sudo systemctl status serial-getty@ttyAMA0.service
sudo systemctl status serial-getty@ttyAMA10.service
```

**Disable serial-getty:**
```bash
# Pi 4
sudo systemctl stop serial-getty@ttyAMA0.service
sudo systemctl disable serial-getty@ttyAMA0.service

# Pi 5
sudo systemctl stop serial-getty@ttyAMA0.service
sudo systemctl disable serial-getty@ttyAMA0.service
sudo systemctl stop serial-getty@ttyAMA10.service
sudo systemctl disable serial-getty@ttyAMA10.service
```

#### Complete Configuration Check Script

Run this to verify all boot configuration is correct:

```bash
#!/bin/bash
echo "=== Checking /boot/firmware/config.txt ==="

# I2C
if grep -q "^dtparam=i2c_arm=on" /boot/firmware/config.txt; then
    echo "[OK] I2C enabled"
else
    echo "[MISSING] dtparam=i2c_arm=on"
fi

# UART
if grep -q "^enable_uart=1" /boot/firmware/config.txt; then
    echo "[OK] UART enabled"
else
    echo "[MISSING] enable_uart=1"
fi

# Bluetooth disabled
if grep -q "^dtoverlay=disable-bt" /boot/firmware/config.txt; then
    echo "[OK] Bluetooth disabled for UART"
else
    echo "[MISSING] dtoverlay=disable-bt"
fi

# Pi 5 specific
if grep -q "Raspberry Pi 5" /proc/device-tree/model 2>/dev/null; then
    echo "Detected: Raspberry Pi 5"
    if grep -A5 "^\[pi5\]" /boot/firmware/config.txt | grep -q "dtoverlay=uart0-pi5"; then
        echo "[OK] Pi 5 UART overlay configured"
    else
        echo "[MISSING] [pi5] section with dtoverlay=uart0-pi5"
    fi
fi

echo ""
echo "=== Checking devices ==="
[ -e /dev/i2c-1 ] && echo "[OK] /dev/i2c-1 exists" || echo "[MISSING] /dev/i2c-1"
[ -e /dev/ttyAMA0 ] && echo "[OK] /dev/ttyAMA0 exists" || echo "[MISSING] /dev/ttyAMA0"

echo ""
echo "=== Checking cmdline.txt for serial console ==="
if grep -q "console=serial0\|console=ttyAMA0" /boot/firmware/cmdline.txt; then
    echo "[WARNING] Serial console enabled - may conflict with FC"
else
    echo "[OK] No serial console conflict"
fi
```

#### When to Rerun Setup Script

If your boot configuration is incorrect, the setup scripts will fix it automatically:

```bash
# Ubuntu 22.04
sudo ./scripts/setup_22_04.sh

# Ubuntu 24.04
sudo ./scripts/setup_24_04.sh

# Always reboot after running setup
sudo reboot
```

---

### I2C LiDAR Issues

#### Permission Denied: `/dev/i2c-1`

**Cause:** User not in i2c group.

**Solution:**
```bash
# Add user, pi for example, to i2c group
sudo usermod -a -G i2c $USER

# Verify
groups  # Should include i2c

# Log out and back in (or reboot)
logout
```

---

#### No Device at Address 0x08

**Check:**
```bash
i2cdetect -y 1
# Should show "08" in the grid
```

**Solutions:**
1. **Check power:**
   - Verify LiDAR has power (VCC, GND connected)
   - Check voltage (typically 3.3V or 5V)

2. **Check wiring:**
   - SDA → GPIO2 (Pin 3)
   - SCL → GPIO3 (Pin 5)
   - VCC → 3.3V or 5V
   - GND → Ground

3. **Check I2C enabled:**
   ```bash
   # Edit config
   sudo nano /boot/firmware/config.txt

   # Add or uncomment:
   dtparam=i2c_arm=on

   # Reboot
   sudo reboot
   ```

4. **Check I2C module:**
   ```bash
   lsmod | grep i2c
   # Should show i2c_dev

   # If not:
   sudo modprobe i2c-dev
   ```

---

#### LiDAR Node Crashes

**Check logs:**
```bash
pm2 logs lidar_reader --lines 50
```

**Common issues:**
- I2C device not found → See above
- Wrong address → Check `swarm_params.yaml` i2c_address
- Bus error → Check wiring, add pull-up resistors if needed

---

### Flight Controller UART Issues

#### Permission Denied: `/dev/ttyAMA0`

**Cause:** User not in dialout group.

**Solution:**
```bash
# Add user to dialout group
sudo usermod -a -G dialout $USER

# Verify
groups  # Should include dialout

# Log out and back in (or reboot)
logout
```

---

#### UART Device Not Found

**Check:**
```bash
ls -l /dev/ttyAMA0
# Should exist with dialout group
```

**Solutions:**
1. **Enable UART:**
   ```bash
   sudo nano /boot/firmware/config.txt

   # Add:
   enable_uart=1

   # Reboot
   sudo reboot
   ```

2. **Disable serial console:**
   ```bash
   # Backup first
   sudo cp /boot/firmware/cmdline.txt /boot/firmware/cmdline.txt.backup

   # Edit
   sudo nano /boot/firmware/cmdline.txt

   # Remove:
   console=serial0,115200
   console=ttyAMA0,115200

   # Reboot
   sudo reboot
   ```

3. **Check alternative devices:**
   ```bash
   ls -l /dev/ttyUSB*
   ls -l /dev/ttyACM*

   # If using USB adapter, update swarm_params.yaml:
   # serial_port: "/dev/ttyUSB0"
   ```

---

#### Flight Controller Not Responding

**Check connection:**
```bash
# Verify device exists
ls -l /dev/ttyAMA0

# Check if in use
sudo lsof /dev/ttyAMA0
# Should show only fc_comms_node or nothing
```

**Check FC comms logs:**
```bash
pm2 logs fc_comms --lines 50
# Should show GPS, attitude, altitude data
```

**Solutions:**
1. **Restart FC physically**
2. **Check wiring:**
   - TX (FC) → RX (Pi)
   - RX (FC) → TX (Pi)
   - GND → GND
3. **Verify baud rate:**
   - Should be 115200 in both INAV and swarm_params.yaml
4. **Check MSP enabled in INAV**
5. **Disable serial conflicts:**
   ```bash
   sudo systemctl stop serial-getty@ttyAMA0
   sudo systemctl disable serial-getty@ttyAMA0
   ```

---

### GPS Issues

#### No GPS Fix

**Symptoms:**
- GPS position shows 0,0
- GPS satellite count is 0
- HDOP is very high

**Solutions:**
1. **Move to open sky location**
   - Away from buildings
   - Clear view of sky
   - No metal structures nearby

2. **Wait for GPS lock**
   - Can take 30-60 seconds from cold start
   - Check satellite count:
     ```bash
     ros2 topic echo /fc/gps_position
     ```

3. **Check GPS satellites:**
   ```bash
   # Monitor in real-time
   ros2 topic echo /fc/gps_speed_course
   ```

4. **Verify GPS connected to FC properly**

5. **Check min_gps_satellites parameter:**
   - Default is 5
   - May need to lower to 4 in poor conditions
   - See CONFIG_PARAMS_GUIDE.md

---

## Build & Installation Issues

### Permission Errors During Build

#### `Permission denied: 'log/build_XXXX'`

**Cause:** Workspace owned by root (ran setup with sudo).

**Solution:**
```bash
# Fix ownership
cd ~/swarm-ros
sudo chown -R $USER:$USER ~/swarm-ros

# Clean old builds
rm -rf log build install

# Rebuild
colcon build --symlink-install
```

---

### CMake or Compilation Errors

**Solutions:**
```bash
# Install missing dependencies
rosdep install --from-paths src --ignore-src -r -y

# Clean and rebuild
cd ~/swarm-ros
rm -rf build install log
colcon build --symlink-install
```

---

### Python Import Errors

#### System packages missing

**Solution:**
```bash
# Reinstall system Python dependencies
pip3 install --upgrade numpy scipy pyserial smbus2
```

#### AI packages missing

**Solution:**
```bash
# Reinstall in virtual environment
source ~/ai_flight_node_env/bin/activate
pip install --upgrade pip
pip install -r ~/swarm-ros/requirements.txt
deactivate
```

---

### Virtual Environment Issues

#### Venv in wrong location (`/root/ai_flight_node_env`)

**Solution:**
```bash
# Remove incorrect venv
sudo rm -rf /root/ai_flight_node_env

# Create in correct location
python3 -m venv ~/ai_flight_node_env
~/ai_flight_node_env/bin/pip install --upgrade pip
~/ai_flight_node_env/bin/pip install -r ~/swarm-ros/requirements.txt
```

---

## Network & Connectivity Issues

### Cannot Connect to Swarm_AP WiFi

**Check WiFi manager:**
```bash
# Check service status
sudo systemctl status wifi-manager.service

# Check hostapd (Access Point)
sudo systemctl status hostapd

# Check dnsmasq (DHCP server)
sudo systemctl status dnsmasq
```

**Solutions:**
```bash
# Restart WiFi manager
sudo systemctl restart wifi-manager.service

# Check logs
sudo journalctl -u wifi-manager.service -f

# Manually start AP mode
sudo systemctl start hostapd
sudo systemctl start dnsmasq
```

---

### WiFi Not Switching to Known Network

**Check configuration:**
```bash
# Verify networks file
cat /etc/wifi_networks.conf

# Should show:
# SSID:password
# MyNetwork:mypassword

# Edit if needed
sudo nano /etc/wifi_networks.conf
```

**Restart manager:**
```bash
sudo systemctl restart wifi-manager.service
```

**Manual scan:**
```bash
nmcli dev wifi list
```

---

### Ethernet Connection Not Working

**Check configuration:**
```bash
# Check eth0 IP
ip addr show eth0
# Should show: inet 192.168.10.1/24

# Check Netplan config
cat /etc/netplan/99-swarm-network.yaml

# Reapply if needed
sudo netplan apply
```

**Check laptop configuration:**
- Laptop must be on 192.168.10.x subnet (x ≠ 1)
- Example: 192.168.10.100

---

### Cannot SSH to 192.168.10.1

**Diagnostics:**
```bash
# From laptop, check connectivity
ping 192.168.10.1

# Check your IP
ip addr
# Should be 192.168.10.x

# Try verbose SSH
ssh -vvv pi@192.168.10.1
```

**Check SSH service on drone:**
```bash
sudo systemctl status ssh
sudo systemctl start ssh
```

---

## Runtime & Node Issues

### Node Crashes Immediately

**Check logs:**
```bash
pm2 logs <node_name> --lines 50
```

**Common issues by node:**

| Node | Common Issue | Solution |
|---|---|---|
| lidar_reader | I2C device not found | Check `i2cdetect -y 1` |
| fc_comms | Serial permission denied | Add user to dialout group |
| ai_flight | Model file not found | Verify model path |
| fc_adapter | MSP timeout | Check FC connection |

---

### No Data on Topics

**Check node is running:**
```bash
ros2 node list
# Should show all nodes
```

**Monitor topic:**
```bash
ros2 topic echo /ai/action
# Press Ctrl+C to stop
```

**Check publishers:**
```bash
ros2 topic info /ai/action
# Shows number of publishers/subscribers
```

**Common causes:**
- Node crashed → Check PM2 logs
- Parameter misconfigured → Check swarm_params.yaml
- Hardware disconnected → Check hardware
- Network issues → Check ROS_DOMAIN_ID

---

### AI Model Not Loading

**Check model exists:**
```bash
ls -lh ~/swarm-ros/model/UID_3.zip
# Should exist and be readable
```

**Check virtual environment:**
```bash
ls -ld ~/ai_flight_node_env
# Should exist

~/ai_flight_node_env/bin/python --version
# Should show Python 3.x
```

**Test PyTorch:**
```bash
~/ai_flight_node_env/bin/python -c "import torch; print(torch.__version__)"
# Should print version without errors
```

**Reinstall packages:**
```bash
~/ai_flight_node_env/bin/pip install -r ~/swarm-ros/requirements.txt
```
---

## Parameter & Configuration Issues

### Node Fails to Start

#### Invalid Parameter File Syntax

**Check YAML syntax:**
```bash
python3 -c "import yaml; yaml.safe_load(open('swarm_params.yaml'))"
```

**Common YAML errors:**
- Wrong indentation (use spaces, not tabs)
- Missing colons
- Unclosed brackets/quotes

---

#### Parameter Names Mismatch

**Check:**
- Must exactly match declared parameters in code
- Case-sensitive
- Underscores vs hyphens matter

**Verify loading:**
```bash
ros2 param list /node_name
ros2 param get /node_name parameter_name
```

---

### Parameters Not Applied

**Check launch file:**
```bash
# Verify parameters are loaded
ros2 param list /fc_adapter_node

# Check specific value
ros2 param get /fc_adapter_node max_velocity
```

**Ensure launch file loads config:**
- Check `parameters=[config]` in launch file
- Verify config file path is correct

---

### Invalid Parameter Values

**Check node logs:**
```bash
pm2 logs node_name
# or
ros2 run swarm_ai_integration node_name.py
```

Most nodes validate parameters and log warnings.

**Common issues:**
- Values out of range
- Wrong type (string vs number)
- Missing required parameter

**See:** CONFIG_PARAMS_GUIDE.md for valid ranges

---

## Performance Issues

### High CPU Usage

**Check stats:**
```bash
pm2 list
pm2 monit
top
```

**Common causes:**
1. **Control rates too high:**
   ```yaml
   control_rate_hz: 30  # Reduce from 40
   telemetry_rate: 20   # Reduce from 30
   prediction_rate: 8   # Reduce from 10
   ```

2. **Too many nodes logging:**
   - Disable debug logging
   - Reduce log rates

3. **AI inference slow:**
   - Check model on correct device (CPU vs GPU)
   - Reduce prediction_rate

4. **Serial communication issues:**
   - Check for errors in fc_comms logs

---

### High Memory Usage

**Check memory:**
```bash
free -h
pm2 monit
```

**Solutions:**
1. **Reduce buffer sizes:**
   ```yaml
   action_buffer_size: 10  # Reduce from 25
   log_buffer_size: 500    # Reduce from 1000
   ```

2. **Reduce log file sizes:**
   ```yaml
   max_log_file_size_mb: 50  # Reduce from 100
   ```

3. **Clear old logs:**
   ```bash
   pm2 flush
   rm ~/swarm-ros/flight-logs/*.csv
   ```

---

### Delayed Responses

**Check rates:**
```bash
# Topic publish rates
ros2 topic hz /ai/action
ros2 topic hz /fc/gps_position
```

**Solutions:**
1. **Increase rates (if CPU allows):**
   ```yaml
   control_rate_hz: 40-50
   telemetry_rate: 30-40
   prediction_rate: 10-15
   ```

2. **Check network latency:**
   ```bash
   # Check ROS_DOMAIN_ID
   echo $ROS_DOMAIN_ID

   # Ping between devices if distributed
   ping <other_device_ip>
   ```

3. **Reduce QoS depths:**
   ```yaml
   sensor_qos_depth: 1  # Use latest only
   ```

---

## Safety & Emergency Procedures

### Emergency Stop

**Immediate actions:**
1. **Kill throttle on RC transmitter**
   - Manual override always available
   - Disarm switch

2. **Stop PM2 processes:**
   ```bash
   pm2 stop all
   ```

3. **Kill ROS2:**
   ```bash
   pkill -9 ros
   pkill -9 python3
   ```

---

### Safety Override Triggered

**Check safety monitor:**
```bash
ros2 topic echo /fc_adapter/status
ros2 topic echo /safety/override
```

**Common triggers:**
- Altitude exceeded
- Distance from home exceeded
- Roll/pitch angle exceeded
- Battery too low
- GPS lost

**Check limits in swarm_params.yaml:**
```yaml
safety_monitor_node:
  ros__parameters:
    max_altitude: 10.0
    max_distance_from_home: 50.0
    max_roll_angle: 15.0
    max_pitch_angle: 15.0
```

---

### Lost GPS During Flight

**Automatic response:**
- Safety monitor activates
- RTH may engage (if configured)
- Hover mode activated

**Manual intervention:**
1. **Switch to manual mode**
2. **Land immediately**
3. **Don't rely on GPS navigation**

---

### Communication Lost with FC

**Symptoms:**
- No telemetry data
- FC not responding to commands

**Immediate actions:**
1. **Check FC powered**
2. **Manual RC takeover**
3. **Land safely**

**Debug after landing:**
```bash
# Check serial connection
ls -l /dev/ttyAMA0
sudo lsof /dev/ttyAMA0

# Check logs
pm2 logs fc_comms --lines 100
```

---

## Related Documentation

- [Setup Guide](SETUP_GUIDE.md) - Installation and configuration
- [Commands Guide](COMMANDS_GUIDE.md) - System operation commands
- [INAV Guide](INAV_GUIDE.md) - Flight controller parameters
- [Config Params Guide](CONFIG_PARAMS_GUIDE.md) - ROS2 parameters

---

## Getting Help

### Deep Dive Articles

For background context that may help with troubleshooting, check out our Substack series:
- [Chapter 1: Inside the Drone](https://substack.com/home/post/p-175604069) — Hardware components and drone anatomy
- [Chapter 2: The Wiring Brain](https://substack.com/home/post/p-176136139) — Wiring, connections, and power distribution
- [Chapter 3: From Data to Motion](https://substack.com/home/post/p-177453660) — Software architecture and data flow
- [Chapter 3.5: Additional Configurations](https://substack.com/home/post/p-180586067) — Advanced configuration and tuning

### Collecting Diagnostic Information

Before reporting issues, collect:

```bash
# System info
uname -a
cat /etc/os-release

# ROS2 info
echo $ROS_DISTRO
ros2 doctor

# Node status
ros2 node list
ros2 topic list

# PM2 status
pm2 list

# Hardware status
i2cdetect -y 1
ls -l /dev/ttyAMA0
groups

# Logs
pm2 logs --lines 200 > pm2_logs.txt
journalctl -u wifi-manager.service > wifi_logs.txt

# Configuration
cat ~/swarm-ros/src/swarm_ai_integration/config/swarm_params.yaml
```

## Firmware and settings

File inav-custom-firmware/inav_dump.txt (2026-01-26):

Entering CLI Mode, type 'exit' to return, or 'help'

# dump

# version
# INAV/SPEEDYBEEF405V4 8.0.1 Sep 30 2025 / 18:19:26 (ae47bcba) 
# GCC-13.2.1 20231009

# start the command batch
batch start

# resources

# Timer overrides
timer_output_mode 0 AUTO
timer_output_mode 1 AUTO
timer_output_mode 2 AUTO
timer_output_mode 3 AUTO
timer_output_mode 4 AUTO
timer_output_mode 5 AUTO
timer_output_mode 6 AUTO
timer_output_mode 7 AUTO
timer_output_mode 8 AUTO
timer_output_mode 9 AUTO
timer_output_mode 10 AUTO
timer_output_mode 11 AUTO
timer_output_mode 12 AUTO
timer_output_mode 13 AUTO

# Outputs [servo]
servo 0 1000 2000 1500 100
servo 1 1000 2000 1500 100
servo 2 1000 2000 1500 100
servo 3 1000 2000 1500 100
servo 4 1000 2000 1500 100
servo 5 1000 2000 1500 100
servo 6 1000 2000 1500 100
servo 7 1000 2000 1500 100
servo 8 1000 2000 1500 100
servo 9 1000 2000 1500 100
servo 10 1000 2000 1500 100
servo 11 1000 2000 1500 100
servo 12 1000 2000 1500 100
servo 13 1000 2000 1500 100
servo 14 1000 2000 1500 100
servo 15 1000 2000 1500 100
servo 16 1000 2000 1500 100
servo 17 1000 2000 1500 100

# safehome
safehome 0 0 0 0
safehome 1 0 0 0
safehome 2 0 0 0
safehome 3 0 0 0
safehome 4 0 0 0
safehome 5 0 0 0
safehome 6 0 0 0
safehome 7 0 0 0

# Fixed Wing Approach
fwapproach 0 0 0 0 0 0 0
fwapproach 1 0 0 0 0 0 0
fwapproach 2 0 0 0 0 0 0
fwapproach 3 0 0 0 0 0 0
fwapproach 4 0 0 0 0 0 0
fwapproach 5 0 0 0 0 0 0
fwapproach 6 0 0 0 0 0 0
fwapproach 7 0 0 0 0 0 0
fwapproach 8 0 0 0 0 0 0
fwapproach 9 0 0 0 0 0 0
fwapproach 10 0 0 0 0 0 0
fwapproach 11 0 0 0 0 0 0
fwapproach 12 0 0 0 0 0 0
fwapproach 13 0 0 0 0 0 0
fwapproach 14 0 0 0 0 0 0
fwapproach 15 0 0 0 0 0 0
fwapproach 16 0 0 0 0 0 0

# geozone
geozone 0 0 0 0 0 0 0 0
geozone 1 0 0 0 0 0 0 0
geozone 2 0 0 0 0 0 0 0
geozone 3 0 0 0 0 0 0 0
geozone 4 0 0 0 0 0 0 0
geozone 5 0 0 0 0 0 0 0
geozone 6 0 0 0 0 0 0 0
geozone 7 0 0 0 0 0 0 0
geozone 8 0 0 0 0 0 0 0
geozone 9 0 0 0 0 0 0 0
geozone 10 0 0 0 0 0 0 0
geozone 11 0 0 0 0 0 0 0
geozone 12 0 0 0 0 0 0 0
geozone 13 0 0 0 0 0 0 0
geozone 14 0 0 0 0 0 0 0
geozone 15 0 0 0 0 0 0 0
geozone 16 0 0 0 0 0 0 0
geozone 17 0 0 0 0 0 0 0
geozone 18 0 0 0 0 0 0 0
geozone 19 0 0 0 0 0 0 0
geozone 20 0 0 0 0 0 0 0
geozone 21 0 0 0 0 0 0 0
geozone 22 0 0 0 0 0 0 0
geozone 23 0 0 0 0 0 0 0
geozone 24 0 0 0 0 0 0 0
geozone 25 0 0 0 0 0 0 0
geozone 26 0 0 0 0 0 0 0
geozone 27 0 0 0 0 0 0 0
geozone 28 0 0 0 0 0 0 0
geozone 29 0 0 0 0 0 0 0
geozone 30 0 0 0 0 0 0 0
geozone 31 0 0 0 0 0 0 0
geozone 32 0 0 0 0 0 0 0
geozone 33 0 0 0 0 0 0 0
geozone 34 0 0 0 0 0 0 0
geozone 35 0 0 0 0 0 0 0
geozone 36 0 0 0 0 0 0 0
geozone 37 0 0 0 0 0 0 0
geozone 38 0 0 0 0 0 0 0
geozone 39 0 0 0 0 0 0 0
geozone 40 0 0 0 0 0 0 0
geozone 41 0 0 0 0 0 0 0
geozone 42 0 0 0 0 0 0 0
geozone 43 0 0 0 0 0 0 0
geozone 44 0 0 0 0 0 0 0
geozone 45 0 0 0 0 0 0 0
geozone 46 0 0 0 0 0 0 0
geozone 47 0 0 0 0 0 0 0
geozone 48 0 0 0 0 0 0 0
geozone 49 0 0 0 0 0 0 0
geozone 50 0 0 0 0 0 0 0
geozone 51 0 0 0 0 0 0 0
geozone 52 0 0 0 0 0 0 0
geozone 53 0 0 0 0 0 0 0
geozone 54 0 0 0 0 0 0 0
geozone 55 0 0 0 0 0 0 0
geozone 56 0 0 0 0 0 0 0
geozone 57 0 0 0 0 0 0 0
geozone 58 0 0 0 0 0 0 0
geozone 59 0 0 0 0 0 0 0
geozone 60 0 0 0 0 0 0 0
geozone 61 0 0 0 0 0 0 0
geozone 62 0 0 0 0 0 0 0

# geozone vertices
geozone vertex -1 0 0 0
geozone vertex -1 0 0 0
geozone vertex -1 0 0 0
geozone vertex -1 0 0 0
geozone vertex -1 0 0 0
geozone vertex -1 0 0 0
geozone vertex -1 0 0 0
geozone vertex -1 0 0 0
geozone vertex -1 0 0 0
geozone vertex -1 0 0 0
geozone vertex -1 0 0 0
geozone vertex -1 0 0 0
geozone vertex -1 0 0 0
geozone vertex -1 0 0 0
geozone vertex -1 0 0 0
geozone vertex -1 0 0 0
geozone vertex -1 0 0 0
geozone vertex -1 0 0 0
geozone vertex -1 0 0 0
geozone vertex -1 0 0 0
geozone vertex -1 0 0 0
geozone vertex -1 0 0 0
geozone vertex -1 0 0 0
geozone vertex -1 0 0 0
geozone vertex -1 0 0 0
geozone vertex -1 0 0 0
geozone vertex -1 0 0 0
geozone vertex -1 0 0 0
geozone vertex -1 0 0 0
geozone vertex -1 0 0 0
geozone vertex -1 0 0 0
geozone vertex -1 0 0 0
geozone vertex -1 0 0 0
geozone vertex -1 0 0 0
geozone vertex -1 0 0 0
geozone vertex -1 0 0 0
geozone vertex -1 0 0 0
geozone vertex -1 0 0 0
geozone vertex -1 0 0 0
geozone vertex -1 0 0 0
geozone vertex -1 0 0 0
geozone vertex -1 0 0 0
geozone vertex -1 0 0 0
geozone vertex -1 0 0 0
geozone vertex -1 0 0 0
geozone vertex -1 0 0 0
geozone vertex -1 0 0 0
geozone vertex -1 0 0 0
geozone vertex -1 0 0 0
geozone vertex -1 0 0 0
geozone vertex -1 0 0 0
geozone vertex -1 0 0 0
geozone vertex -1 0 0 0
geozone vertex -1 0 0 0
geozone vertex -1 0 0 0
geozone vertex -1 0 0 0
geozone vertex -1 0 0 0
geozone vertex -1 0 0 0
geozone vertex -1 0 0 0
geozone vertex -1 0 0 0
geozone vertex -1 0 0 0
geozone vertex -1 0 0 0
geozone vertex -1 0 0 0
geozone vertex -1 0 0 0
geozone vertex -1 0 0 0
geozone vertex -1 0 0 0
geozone vertex -1 0 0 0
geozone vertex -1 0 0 0
geozone vertex -1 0 0 0
geozone vertex -1 0 0 0
geozone vertex -1 0 0 0
geozone vertex -1 0 0 0
geozone vertex -1 0 0 0
geozone vertex -1 0 0 0
geozone vertex -1 0 0 0
geozone vertex -1 0 0 0
geozone vertex -1 0 0 0
geozone vertex -1 0 0 0
geozone vertex -1 0 0 0
geozone vertex -1 0 0 0
geozone vertex -1 0 0 0
geozone vertex -1 0 0 0
geozone vertex -1 0 0 0
geozone vertex -1 0 0 0
geozone vertex -1 0 0 0
geozone vertex -1 0 0 0
geozone vertex -1 0 0 0
geozone vertex -1 0 0 0
geozone vertex -1 0 0 0
geozone vertex -1 0 0 0
geozone vertex -1 0 0 0
geozone vertex -1 0 0 0
geozone vertex -1 0 0 0
geozone vertex -1 0 0 0
geozone vertex -1 0 0 0
geozone vertex -1 0 0 0
geozone vertex -1 0 0 0
geozone vertex -1 0 0 0
geozone vertex -1 0 0 0
geozone vertex -1 0 0 0
geozone vertex -1 0 0 0
geozone vertex -1 0 0 0
geozone vertex -1 0 0 0
geozone vertex -1 0 0 0
geozone vertex -1 0 0 0
geozone vertex -1 0 0 0
geozone vertex -1 0 0 0
geozone vertex -1 0 0 0
geozone vertex -1 0 0 0
geozone vertex -1 0 0 0
geozone vertex -1 0 0 0
geozone vertex -1 0 0 0
geozone vertex -1 0 0 0
geozone vertex -1 0 0 0
geozone vertex -1 0 0 0
geozone vertex -1 0 0 0
geozone vertex -1 0 0 0
geozone vertex -1 0 0 0
geozone vertex -1 0 0 0
geozone vertex -1 0 0 0
geozone vertex -1 0 0 0
geozone vertex -1 0 0 0
geozone vertex -1 0 0 0
geozone vertex -1 0 0 0
geozone vertex -1 0 0 0
geozone vertex -1 0 0 0

# features
feature -THR_VBAT_COMP
feature -VBAT
feature -TX_PROF_SEL
feature -BAT_PROF_AUTOSWITCH
feature -GEOZONE
feature -SOFTSERIAL
feature -GPS
feature -RPM_FILTERS
feature -TELEMETRY
feature -CURRENT_METER
feature -REVERSIBLE_MOTORS
feature -RSSI_ADC
feature -LED_STRIP
feature -DASHBOARD
feature -BLACKBOX
feature -TRANSPONDER
feature -AIRMODE
feature -SUPEREXPO
feature -VTX
feature -PWM_OUTPUT_ENABLE
feature -OSD
feature -FW_LAUNCH
feature -FW_AUTOTRIM
feature VBAT
feature TX_PROF_SEL
feature GPS
feature TELEMETRY
feature CURRENT_METER
feature BLACKBOX
feature AIRMODE
feature PWM_OUTPUT_ENABLE
feature OSD

# beeper
beeper RUNTIME_CALIBRATION
beeper HW_FAILURE
beeper RX_LOST
beeper RX_LOST_LANDING
beeper DISARMING
beeper ARMING
beeper ARMING_GPS_FIX
beeper BAT_CRIT_LOW
beeper BAT_LOW
beeper GPS_STATUS
beeper RX_SET
beeper ACTION_SUCCESS
beeper ACTION_FAIL
beeper READY_BEEP
beeper MULTI_BEEPS
beeper DISARM_REPEAT
beeper ARMED
beeper SYSTEM_INIT
beeper ON_USB
beeper LAUNCH_MODE
beeper LAUNCH_MODE_LOW_THROTTLE
beeper LAUNCH_MODE_IDLE_START
beeper CAM_CONNECTION_OPEN
beeper CAM_CONNECTION_CLOSED

# blackbox
blackbox -NAV_ACC
blackbox NAV_POS
blackbox NAV_PID
blackbox MAG
blackbox ACC
blackbox ATTI
blackbox RC_DATA
blackbox RC_COMMAND
blackbox MOTORS
blackbox -GYRO_RAW
blackbox -PEAKS_R
blackbox -PEAKS_P
blackbox -PEAKS_Y
blackbox SERVOS

# Receiver: Channel map
map AETR

# Ports
serial 20 1 115200 115200 0 115200
serial 0 1 115200 115200 0 115200
serial 1 64 115200 115200 0 115200
serial 2 1 115200 115200 0 115200
serial 3 0 115200 115200 0 115200
serial 4 262144 115200 115200 0 115200
serial 5 2 115200 57600 0 115200
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

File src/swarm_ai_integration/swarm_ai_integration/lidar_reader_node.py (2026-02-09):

#!/usr/bin/env python3
"""
LiDAR Reader Node - I2C Protocol Implementation

This node reads distance data from LiDAR sensors via I2C communication.
It supports multiple sensor instances for different mounting positions (front, down, etc.).

I2C Protocol:
- I2C Address: 0x08 (default)
- Distance Register: 0x24 (base address for distance data)
- Data Format: 4 bytes, little-endian uint32 representing distance in millimeters
- Conversion: distance_mm / 1000.0 = distance in meters

The node publishes sensor_msgs/Range messages containing distance measurements
and provides diagnostic information about sensor health and data quality.
"""

import rclpy
from rclpy.node import Node
from rclpy.qos import QoSProfile, QoSReliabilityPolicy, QoSHistoryPolicy

from sensor_msgs.msg import Range
from std_msgs.msg import Header, Float32MultiArray, String, Bool
from geometry_msgs.msg import PointStamped

from smbus2 import SMBus
import struct
import time
import threading
from typing import Optional, Tuple, Dict, Any
from collections import deque
import numpy as np


class LidarReaderNode(Node):
    """
    LiDAR Reader Node for I2C-based LiDAR sensors.

    This node handles I2C communication with LiDAR sensors,
    reads distance data, and publishes ROS2 Range messages.

    Publishers:
        /lidar_distance (sensor_msgs/Range): Distance measurements
        /lidar_raw (std_msgs/Float32MultiArray): Raw sensor data
        /lidar_status (std_msgs/String): Sensor status and diagnostics
        /lidar_point (geometry_msgs/PointStamped): 3D point in sensor frame
    """

    def __init__(self):
        super().__init__('lidar_reader_node')

        # Declare parameters
        # I2C communication
        self.declare_parameter('i2c_bus', 1)  # I2C bus number
        self.declare_parameter('i2c_address', 0x08)  # I2C device address
        self.declare_parameter('distance_register', 0x24)  # Distance data register

        # Sensor configuration
        self.declare_parameter('publish_rate', 100.0)  # Hz (max 100Hz per specs)
        self.declare_parameter('frame_id', 'lidar_link')
        self.declare_parameter('sensor_position', 'down')  # front, down, etc.

        # Range limits
        self.declare_parameter('max_range', 50.0)  # Maximum valid range (meters)
        self.declare_parameter('min_range', 0.05)  # Minimum valid range (meters)
        self.declare_parameter('field_of_view', 0.035)  # FOV in radians (~2 degrees)

        # Data processing
        self.declare_parameter('enable_filtering', True)  # Enable distance filtering
        self.declare_parameter('filter_window_size', 5)  # Moving average filter size
        self.declare_parameter('max_invalid_readings', 10)  # Max consecutive invalid readings

        # Timing
        self.declare_parameter('status_publish_interval', 1.0)  # Status publishing interval (seconds)
        self.declare_parameter('reconnect_interval', 5.0)  # I2C reconnection interval (seconds)

        # QoS settings
        self.declare_parameter('sensor_qos_depth', 1)  # QoS depth for sensor data
        self.declare_parameter('reliable_qos_depth', 10)  # QoS depth for reliable data

        # Conversion
        self.declare_parameter('mm_to_m_divisor', 1000.0)  # Millimeter to meter conversion

        # Get parameters
        self.i2c_bus = self.get_parameter('i2c_bus').get_parameter_value().integer_value
        self.i2c_address = self.get_parameter('i2c_address').get_parameter_value().integer_value
        self.distance_register = self.get_parameter('distance_register').get_parameter_value().integer_value
        self.publish_rate = self.get_parameter('publish_rate').get_parameter_value().double_value
        self.frame_id = self.get_parameter('frame_id').get_parameter_value().string_value
        self.sensor_position = self.get_parameter('sensor_position').get_parameter_value().string_value
        self.max_range = self.get_parameter('max_range').get_parameter_value().double_value
        self.min_range = self.get_parameter('min_range').get_parameter_value().double_value
        self.field_of_view = self.get_parameter('field_of_view').get_parameter_value().double_value
        self.enable_filtering = self.get_parameter('enable_filtering').get_parameter_value().bool_value
        self.filter_window_size = self.get_parameter('filter_window_size').get_parameter_value().integer_value
        self.max_invalid_readings = self.get_parameter('max_invalid_readings').get_parameter_value().integer_value
        self.status_publish_interval = self.get_parameter('status_publish_interval').get_parameter_value().double_value
        self.reconnect_interval = self.get_parameter('reconnect_interval').get_parameter_value().double_value
        self.sensor_qos_depth = self.get_parameter('sensor_qos_depth').get_parameter_value().integer_value
        self.reliable_qos_depth = self.get_parameter('reliable_qos_depth').get_parameter_value().integer_value
        self.mm_to_m_divisor = self.get_parameter('mm_to_m_divisor').get_parameter_value().double_value

        # I2C connection
        self.i2c_bus_conn: Optional[SMBus] = None
        self.i2c_lock = threading.Lock()

        # Data processing
        self.distance_filter = deque(maxlen=self.filter_window_size)
        self.last_valid_distance = 0.0
        self.consecutive_invalid_readings = 0

        # Statistics and monitoring
        self.stats = {
            'total_readings': 0,
            'valid_readings': 0,
            'invalid_readings': 0,
            'i2c_errors': 0,
            'out_of_range_readings': 0,
            'last_distance': 0.0,
            'connection_errors': 0
        }

        # Status tracking
        self.sensor_healthy = False
        self.last_reading_time = time.time()

        # QoS profiles
        sensor_qos = QoSProfile(
            reliability=QoSReliabilityPolicy.BEST_EFFORT,
            history=QoSHistoryPolicy.KEEP_LAST,
            depth=self.sensor_qos_depth
        )

        reliable_qos = QoSProfile(
            reliability=QoSReliabilityPolicy.RELIABLE,
            history=QoSHistoryPolicy.KEEP_LAST,
            depth=self.reliable_qos_depth
        )

        # Publishers
        self.range_pub = self.create_publisher(Range, 'lidar_distance', sensor_qos)
        self.raw_pub = self.create_publisher(Float32MultiArray, 'lidar_raw', sensor_qos)
        self.status_pub = self.create_publisher(String, 'lidar_status', reliable_qos)
        self.point_pub = self.create_publisher(PointStamped, 'lidar_point', sensor_qos)
        self.healthy_pub = self.create_publisher(Bool, 'lidar_healthy', reliable_qos)

        # Initialize I2C connection
        self.connect_i2c()

        # Create timer for reading I2C data
        if self.publish_rate > 0:
            timer_period = 1.0 / self.publish_rate
            self.timer = self.create_timer(timer_period, self.timer_callback)

        # Status publishing timer
        self.status_timer = self.create_timer(1.0, self.publish_status)

        print(f'🚀 LiDAR Reader Node Starting:')
        print(f'   • I2C Bus: {self.i2c_bus}')
        print(f'   • Address: 0x{self.i2c_address:02x}')
        print(f'   • Position: {self.sensor_position}')
        print(f'   • Rate: {self.publish_rate} Hz')
        print(f'   • Range: {self.min_range}m - {self.max_range}m')
        print(f'   • Filter: {"ON" if self.enable_filtering else "OFF"}')
        print('-' * 50)

        self.get_logger().info(
            f'LiDAR Reader Node initialized - I2C Bus: {self.i2c_bus}, Address: 0x{self.i2c_address:02x}, '
            f'Position: {self.sensor_position}, Rate: {self.publish_rate} Hz'
        )

    def connect_i2c(self) -> bool:
        """Initialize I2C connection to LiDAR sensor"""
        try:
            with self.i2c_lock:
                if self.i2c_bus_conn:
                    self.i2c_bus_conn.close()

                self.i2c_bus_conn = SMBus(self.i2c_bus)

                # Test connection by trying to read a byte
                _ = self.i2c_bus_conn.read_byte(self.i2c_address)

                self.sensor_healthy = True
                print(f'✓ I2C Connected: Bus {self.i2c_bus}, Address 0x{self.i2c_address:02x}')
                self.get_logger().info(f'I2C bus {self.i2c_bus} connected to address 0x{self.i2c_address:02x}')
                return True

        except Exception as e:
            print(f'✗ I2C Connection Failed: Bus {self.i2c_bus}, Address 0x{self.i2c_address:02x} - {e}')
            self.get_logger().error(f'Failed to connect to I2C device 0x{self.i2c_address:02x} on bus {self.i2c_bus}: {e}')
            self.sensor_healthy = False
            self.stats['connection_errors'] += 1
            if self.i2c_bus_conn:
                try:
                    self.i2c_bus_conn.close()
                except:
                    pass
                self.i2c_bus_conn = None
            return False

    def read_distance_i2c(self) -> Optional[float]:
        """
        Read distance data from I2C sensor.

        Reads 4 bytes from the distance register (0x24) which contains
        distance in millimeters as a little-endian uint32.

        Returns:
            Distance in meters, or None if reading fails
        """
        try:
            with self.i2c_lock:
                if not self.i2c_bus_conn:
                    return None

                # Read 4 bytes from distance register
                data = self.i2c_bus_conn.read_i2c_block_data(self.i2c_address, self.distance_register, 4)

                # Convert to uint32 little-endian and then to meters
                distance_mm = struct.unpack('<I', bytes(data))[0]
                distance_m = distance_mm / self.mm_to_m_divisor

                print(f'📏 Raw I2C Reading: {distance_mm}mm ({distance_m:.3f}m)')

                return distance_m

        except Exception as e:
            self.get_logger().debug(f'I2C read error: {e}')
            self.stats['i2c_errors'] += 1
            return None


    def apply_distance_filter(self, distance: float) -> float:
        """
        Apply moving average filter to distance readings.

        Args:
            distance: Raw distance measurement

        Returns:
            Filtered distance measurement
        """
        if not self.enable_filtering:
            return distance

        # Add to filter window
        self.distance_filter.append(distance)

        # Return moving average
        return float(np.mean(self.distance_filter))

    def validate_distance(self, distance: float) -> bool:
        """
        Validate distance measurement against range criteria.

        Args:
            distance: Distance measurement in meters

        Returns:
            True if distance is valid, False otherwise
        """
        # Check range bounds
        if not (self.min_range <= distance <= self.max_range):
            self.stats['out_of_range_readings'] += 1
            return False

        return True

    def timer_callback(self):
        """Read I2C data and publish distance measurements."""
        if not self.sensor_healthy:
            # Try to reconnect periodically
            if time.time() - self.last_reading_time > 5.0:  # Every 5 seconds
                self.connect_i2c()
            return

        try:
            # Read distance from I2C sensor
            distance_m = self.read_distance_i2c()

            if distance_m is not None:
                self.stats['total_readings'] += 1

                # Validate distance
                if self.validate_distance(distance_m):
                    # Apply filtering
                    filtered_distance = self.apply_distance_filter(distance_m)

                    print(f'✓ Valid Distance: {filtered_distance:.3f}m (pos: {self.sensor_position})')

                    # Update statistics
                    self.stats['valid_readings'] += 1
                    self.stats['last_distance'] = filtered_distance
                    self.last_valid_distance = filtered_distance
                    self.last_reading_time = time.time()
                    self.consecutive_invalid_readings = 0

                    # Publish Range message
                    self.publish_range_message(filtered_distance)

                    # Publish raw data
                    self.publish_raw_data(distance_m)

                    # Publish 3D point
                    self.publish_point_message(filtered_distance)

                else:
                    print(f'✗ Invalid Distance: {distance_m:.3f}m (out of range: {self.min_range}-{self.max_range}m)')
                    self.stats['invalid_readings'] += 1
                    self.consecutive_invalid_readings += 1

                    # If too many consecutive invalid readings, mark sensor as unhealthy
                    if self.consecutive_invalid_readings > self.max_invalid_readings:
                        self.sensor_healthy = False
                        print(f'⚠️  Sensor marked as unhealthy after {self.consecutive_invalid_readings} invalid readings')
                        self.get_logger().warn(
                            f'Too many consecutive invalid readings ({self.consecutive_invalid_readings}), '
                            'marking sensor as unhealthy'
                        )
            else:
                print(f'✗ I2C Read Failed - No data received')
                self.stats['invalid_readings'] += 1
                self.consecutive_invalid_readings += 1

        except Exception as e:
            print(f'💥 Timer Callback Error: {e}')
            self.get_logger().error(f'Unexpected error in timer callback: {e}')
            self.sensor_healthy = False
            self.stats['connection_errors'] += 1

    def publish_range_message(self, distance: float):
        """Publish sensor_msgs/Range message"""
        try:
            msg = Range()
            msg.header.stamp = self.get_clock().now().to_msg()
            msg.header.frame_id = self.frame_id
            msg.radiation_type = Range.INFRARED  # TOF sensors typically use infrared
            msg.field_of_view = self.field_of_view
            msg.min_range = self.min_range
            msg.max_range = self.max_range
            msg.range = distance

            self.range_pub.publish(msg)

        except Exception as e:
            self.get_logger().error(f'Error publishing range message: {e}')

    def publish_raw_data(self, distance: float):
        """Publish raw sensor data for debugging"""
        try:
            raw_msg = Float32MultiArray()
            raw_msg.data = [
                float(distance),  # Distance in meters
                float(time.time())  # ROS timestamp
            ]

            self.raw_pub.publish(raw_msg)

        except Exception as e:
            self.get_logger().error(f'Error publishing raw data: {e}')

    def publish_point_message(self, distance: float):
        """Publish 3D point message in sensor frame"""
        try:
            point_msg = PointStamped()
            point_msg.header.stamp = self.get_clock().now().to_msg()
            point_msg.header.frame_id = self.frame_id

            # Convert distance to 3D point based on sensor position
            if self.sensor_position == 'front':
                # Forward-facing sensor: point along positive X axis
                point_msg.point.x = distance
                point_msg.point.y = 0.0
                point_msg.point.z = 0.0
            elif self.sensor_position == 'down':
                # Downward-facing sensor: point along negative Z axis
                point_msg.point.x = 0.0
                point_msg.point.y = 0.0
                point_msg.point.z = -distance
            else:
                # Default: forward-facing
                point_msg.point.x = distance
                point_msg.point.y = 0.0
                point_msg.point.z = 0.0

            self.point_pub.publish(point_msg)

        except Exception as e:
            self.get_logger().error(f'Error publishing point message: {e}')

    def publish_status(self):
        """Publish sensor status and diagnostics"""
        try:
            # Sensor health status
            health_msg = Bool()
            health_msg.data = self.sensor_healthy
            self.healthy_pub.publish(health_msg)

            # Detailed status message
            if self.stats['total_readings'] > 0:
                success_rate = (self.stats['valid_readings'] / self.stats['total_readings']) * 100
            else:
                success_rate = 0.0

            time_since_last = time.time() - self.last_reading_time

            status_parts = [
                f"Health: {'OK' if self.sensor_healthy else 'ERROR'}",
                f"Position: {self.sensor_position}",
                f"I2C: 0x{self.i2c_address:02x}",
                f"Distance: {self.stats['last_distance']:.3f}m",
                f"Success: {success_rate:.1f}%",
                f"LastRead: {time_since_last:.1f}s ago",
                f"Readings: {self.stats['total_readings']}",
                f"I2C_Errors: {self.stats['i2c_errors']}"
            ]

            status_msg = String()
            status_msg.data = " | ".join(status_parts)
            self.status_pub.publish(status_msg)

        except Exception as e:
            self.get_logger().error(f'Error publishing status: {e}')

    def destroy_node(self):
        """Clean up resources when node is destroyed"""
        try:
            with self.i2c_lock:
                if self.i2c_bus_conn:
                    self.i2c_bus_conn.close()
                    self.get_logger().info(f'I2C bus {self.i2c_bus} closed')
        except Exception as e:
            self.get_logger().debug(f'Error closing I2C bus: {e}')

        super().destroy_node()


def main(args=None):
    rclpy.init(args=args)

    try:
        node = LidarReaderNode()
        rclpy.spin(node)
    except KeyboardInterrupt:
        pass
    except Exception as e:
        print(f'Error: {e}')
    finally:
        if 'node' in locals():
            node.destroy_node()
        rclpy.shutdown()


if __name__ == '__main__':
    main()

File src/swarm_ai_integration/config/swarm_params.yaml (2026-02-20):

# Swarm AI Integration Parameters Configuration
# Complete parameter set for all nodes in the swarm system

# ═══════════════════════════════════════════════════════════════════
# AI Adapter Node Parameters
# ═══════════════════════════════════════════════════════════════════
ai_adapter_node:
  ros__parameters:
    # Observation generation
    telemetry_rate: 30.0                # Observation generation rate (Hz)
    max_ray_distance: 20.0              # Maximum distance for normalization (meters) - MUST MATCH TRAINING
    action_buffer_size: 25              # Number of past actions to buffer

    # Initial position
    relative_start_enu: [0.0, 0.0, 3.0] # Initial relative position [East, North, Up] (meters)

    # GPS settings
    min_gps_satellites: 5                # Minimum GPS satellites for valid fix

    # QoS settings
    sensor_qos_depth: 1                 # QoS depth for sensor topics
    reliable_qos_depth: 10              # QoS depth for reliable topics

# ═══════════════════════════════════════════════════════════════════
# AI Flight Node Parameters
# ═══════════════════════════════════════════════════════════════════
ai_flight_node:
  ros__parameters:
    # Model settings
    model_path: "/home/pi/swarm-ros/model/UID_3.zip"  # Path to trained AI model
    device: "cpu"                       # Computation device (cpu/cuda)

    # Prediction settings
    prediction_rate: 10.0               # AI prediction rate (Hz)

    # QoS settings
    qos_depth: 1                        # QoS depth for AI topics

# ═══════════════════════════════════════════════════════════════════
# Safety Monitor Node Parameters - Simple Safety System
# ═══════════════════════════════════════════════════════════════════
safety_monitor_node:
  ros__parameters:
    # Attitude Limits
    max_roll_angle: 15.0                # Maximum roll angle (degrees)
    max_pitch_angle: 15.0               # Maximum pitch angle (degrees)

    # Altitude Limits
    min_altitude: 0.0                   # Minimum altitude (meters)
    max_altitude: 10.0                  # Maximum altitude (meters)

    # Geofencing
    max_distance_from_home: 50.0       # Maximum distance from home (meters)

    # Safety Action Timing
    hover_duration: 3.0                 # Hover duration before landing (seconds)

    # System Configuration
    monitor_rate: 20.0                  # Safety monitoring rate (Hz)
    qos_depth: 1                        # QoS depth for safety topics

# ═══════════════════════════════════════════════════════════════════
# FC Communications Node Parameters
# ═══════════════════════════════════════════════════════════════════
fc_comms_node:
  ros__parameters:
    # Serial communication
    serial_port: "/dev/ttyAMA0"         # Serial port for INAV communication
    baud_rate: 115200                   # Serial baud rate
    timeout: 1.0                        # Serial timeout (seconds)
    max_rx_buffer_size: 1024            # Maximum receive buffer size (bytes)

    # Connection management
    reconnect_interval: 5.0             # Reconnection attempt interval (seconds)
    telemetry_rate: 10.0                # Telemetry request rate (Hz)
    heartbeat_rate: 1.0                 # Heartbeat rate (Hz)
    heartbeat_timeout: 10.0             # Heartbeat timeout (seconds)
    connection_timeout: 10.0            # Overall connection timeout (seconds)

    # Waypoint polling
    waypoint_poll_mode: "first"         # Waypoint polling mode (first/all/none)
    max_waypoint_cycle: 10              # Maximum waypoint index to cycle through

    # Data processing scales
    imu_scale_accel: 0.01916015625      # IMU accelerometer scale factor (9.81/512.0)
    imu_scale_gyro: 0.001               # IMU gyroscope scale factor
    battery_voltage_scale: 10.0         # Battery voltage divisor (vbat / 10.0)
    battery_current_scale: 100.0        # Battery current divisor (amperage / 100.0)

    # QoS settings
    command_qos_depth: 10               # QoS depth for command topics

    # GPS altitude fallback
    gps_altitude_timeout: 5.0           # GPS altitude valid timeout (seconds)
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

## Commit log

2025-09-29 Wip: changed LiDAR to I2C
2025-09-30 Fix: working on fc_adapter_node
    [pid_controller.py]
2025-10-01 msp_arm -- MSP status fix
    [msp_arm_drone.py]
2025-10-06 Fix: solved bug on ai_adapter
    [sensor_data_manager.py]
2025-10-07 Fix: added custom parser for msp code 100
    [msp_message_parser.py]
2025-10-07 Fix: removed msp code 100 implementation due to be deprecated
    [msp_message_parser.py]
2025-10-07 Fix: solved array past actions error on ai adapter node
    [observation_builder.py]
2025-10-08 Fix: change on fix_type for GPS
    [msp_message_parser.py]
2025-10-08 Feature: implemented HDOP for GPS quality measurement and fixed fix_type error
    [msp_message_parser.py, sensor_data_manager.py, telemetry_publisher.py]
2025-10-08 Fix: small fix on ai_adapter
    [msp_message_parser.py]
2025-10-09 Fix: change in max ray distances for debug
    [observation_builder.py, swarm_params.yaml]
2025-10-10 Fix: new fix for velocity
2025-10-14 Fix: added more Lidar rays to simulator
2025-10-15 Fix: change on observation array to increase action history properly
    [observation_builder.py]
2025-10-16 Feature: added new simulator for wp and landing
2025-10-20 Fix: change on lidar tilded rays
2025-10-23 Fix: change on ai_flight launch script, general launch and swarm params
    [swarm_params.yaml]
2025-10-23 Fix: change on ai node launch script
    [swarm_params.yaml]
2025-10-23 Fix: change on black box directory path
    [swarm_params.yaml]
2025-10-27 Feature: added custom rth and landing in two phases, gps and lidar
2025-10-28 Fix: bugs fixed in setup script
    [swarm_params.yaml]
2025-10-30 Fix: added new simulator and added new altitude msp lecture
    [msp_message_parser.py, telemetry_publisher.py]
2025-11-04 Feature: added new simulator for fc_adapter and fixed fc_adapter speed and yaw
    [swarm_params.yaml]
2025-11-04 Fix: change in model path source
    [swarm_params.yaml]
2025-11-06 Fix: added new parameter to enable/disable yaw
    [swarm_params.yaml]
2025-11-06 Fix: change on config
    [swarm_params.yaml]
2025-11-10 Fix: parameters refactor and new black box
    [lidar_reader_node.py, msp_arm_and_throttle.py, msp_arm_and_throttle_complex.py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]
2025-11-12 Fix: new simplier version of safety monitor
    [safety_monitor_advance_params.txt]
2025-11-13 Fix: change on RC values on flight test
    [flight_test_node.py, swarm_params.yaml]
2025-11-17 Fix: lower RC values and added required linux packages to network setup
    [simple_flight_test_node.py]
2025-11-17 Fix: news change on simple flight test
    [simple_flight_test_node.py]
2025-11-17 Fix: lower rc values for simple flight test
    [simple_flight_test_node.py]
2025-11-17 Fix: complete refactor of simple flight test
    [msp_arm_and_throttle_simple.py, simple_flight_test_node.py]
2025-11-17 Fix: added all channels to rc values on simple flight test
    [simple_flight_test_node.py]
2025-11-17 Fix: minor RC values changes on simple flight test
    [simple_flight_test_node.py]
2025-11-24 Fix: change on manual simple flight test script
    [simple_flight_test_node.py]
2025-11-24 Fix: change on GPS accuracy
    [swarm_params.yaml]
2025-11-27 Feature: new docs folder with more info, changes on main Readme and adjusted throttle during arming phase on fc_adapter
2025-11-28 Fix: change on /src structure and fixed tilted angles rays on ai_adapter_node
    [safety_monitor_advance_params.txt]
2025-12-01 Fix: change on channels values
    [swarm_params.yaml]
2025-12-01 Fix: change on safety monitor
    [swarm_params.yaml]
2025-12-09 Fix: added yaw aligment and corretions on output vector interpretation
    [yaw_alignment.py]
2025-12-15 Chore: deleted last changes of lidar bridge for altitude
2025-12-16 Add section 4 “What is Langostino?”
2025-12-16 Update assembly section in README.md
    Includes the parts list (BOM) and step-by-step build instructions.
2025-12-16 Fix: solved rc transmission gaps and unwanted disarms
    [yaw_alignment.py]
2025-12-16 Feature: added new arm phase the fc_adapter
2025-12-17 Revise wiring instructions in README
    Updated instructions for wiring and quickstart checklist.
2025-12-17 Fix: change on yaw aligment and channel mapping
    [yaw_alignment.py]
2025-12-18 Debug: added logs to see attitude on fc adapter and yaw aligment
2025-12-18 Fix: deleted sleeps and blocking process for continious update on aligment process and more
    [yaw_alignment.py]
2025-12-19 Drone alignment without drift
    [yaw_alignment.py]
2025-12-29 create assembly doc
2025-12-29 modify links buttons
2026-01-03 Update link in "Use Model" button for "SETUP_GUIDE.md#quick-setup"
2026-01-06 Create BOM file
2026-01-09 Fix links and file paths in assembly README
    Updated links and file paths in README.md for accuracy.
2026-01-09 Add BOM for Langostino 6" quadcopter
    This document outlines the parts list for building a Langostino-compatible 6" quadcopter, including required components for the airframe, propulsion, flight control, GPS, radio control, battery, and 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
2026-01-09 Update BOM for Langostino quadcopter
2026-01-21 Fix: fixed bugs on workspace path and uart device address
2026-01-22 STL's uploaded
    [drone-down-lidar-base.stl, drone-front-lidar-base.stl, drone-leg.stl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]
2026-01-22 Fix: solved issue with uart address for rpi5 and properly configured on the setup 24.04 script
2026-01-26 Feature: added fc dump back and updated INAV guide md with the newest config values
    [inav_dump.txt]
2026-02-03 yaw corrected
2026-02-11 Fix: solved some bugs on launch and added emergency landing using altitude
    [emergency_landing.py]
2026-02-15 Feature: new version of rpi case stl
    [drone-raspberry-onboard-case.stl]
2026-02-15 LiDAR inconsistency fix
2026-02-16 height corrected
    [height_0p2s_blackbox_20260203_155600_000.csv]
2026-02-16 improved horizontal velocity
2026-02-16 improved height hold
    [200_arming_altitude_0p5s.csv, 200_arming_altitude_throttle_0p5s.csv]
2026-02-17 Chore: deleted logs
    [200_arming_altitude_0p5s.csv, 200_arming_altitude_throttle_0p5s.csv, height_0p2s_blackbox_20260203_155600_000.csv]
2026-02-18 Fix: changes on test hardcoded
    [test_hardcoded.py]
2026-02-18 3D printer added
2026-02-18 Fix: new version of fc_adapter
    [altitude_hold.py, swarm_params.yaml, test_hardcoded.py]
2026-02-19 Fix: new rising method on fc_adapter
    [rise_controller.py, swarm_params.yaml]
2026-02-19 Fix: solved error on lidar topic reading in fc_adapter
2026-02-20 Fix: change on fc_adapter burst time, added speed multiplier and updated docs with these changes
    [roll_flight_test.py, simple_flight_test.py, swarm_params.yaml]
2026-02-24 Fix: new version of raspberry pi mount case
    [drone-raspberry-onboard-case.stl]

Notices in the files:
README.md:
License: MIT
